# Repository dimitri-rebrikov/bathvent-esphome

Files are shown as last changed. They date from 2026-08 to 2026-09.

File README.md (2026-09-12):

# bathvent-esphome

Automatisierte Lüftungssteuerung für das Bad auf Basis von ESPHome (ESP8266/ESP32) mit MQTT-Anbindung.

## Ziele

Das Projekt steuert die Lüftung eines Bads automatisch anhand von Luftfeuchte und Luftqualität. Die Lüftung soll anwesenheitsabhängig arbeiten – bei Anwesenheit niedrige bis mittlere Stufe, bei Abwesenheit volle Leistung bei überschrittener Schwelle. Schwellwerte und Zeiten sollen zur Laufzeit anpassbar sein; bei Sensorausfall soll die Lüftung weiter funktionieren.

## Umsetzungsideen / Prinzipien

Die Regelung ist eine kleine Zustandsmaschine mit vier Zuständen (`off`, `flush`, `sniff`, `run`) — vollständige Beschreibung inklusive Ablaufdiagramm: [`docs/state-machine.md`](docs/state-machine.md).

Anwesenheit wird über den Lichtschalter erkannt. Bei Anwesenheit startet eine Spülfahrt auf der niedrigsten Stufe; sie spült den Kanal, damit die Messwerte nicht durch zurückströmende Außenluft verfälscht sind. Danach wird gemessen: überschreitet ein Wert seine Schwelle, schaltet der Lüfter auf die mittlere Stufe (begrenzt die Geräuschentwicklung), bei Abwesenheit auf volle Stufe. Bei sauberer Luft und Anwesenheit bleibt er auf der niedrigsten Stufe, bei Abwesenheit aus. Nach dem Ausschalten des Lichts läuft er noch eine Weile auf der niedrigsten Stufe nach; nach langer Abwesenheit wird in Abständen eine Spül-/Messfahrt ausgeführt.

Die Schwellen sind **absolut** (keine gleitende Baseline): Ein Lauf endet, wenn sich in einem vollen Prüfintervall kein Sensorwert mehr signifikant ändert. Das Prüfintervall übernimmt damit die Rolle der Hysterese und begrenzt zugleich, wie oft der Lüfter bei anhaltend feuchter Außenluft anläuft (Frequenz ≈ Prüfintervall + Leerlaufzeit + Spülzeit).

Die drei Stufen werden über eine Kaskadenschaltung realisiert: niedrige und mittlere Stufe über Serien-Kondensatoren, volle Stufe direkt. Die Kaskade verhindert den Kurzschluss der geladenen Kondensatoren, der die Relais beschädigen würde (Festkleben der Kontakte).

Der Feuchtesensor (DHT20) ist der einzige fail-safe-relevante Sensor: Antwortet er nicht (`NAN`), wird sein Messwert durch einen konfigurierbaren Ersatzwert **oberhalb** der Schwelle ersetzt — der Lüfter lüftet dann defensiv weiter (bei Anwesenheit mittlere Stufe, sonst periodischer Volllast-Lauf). Der VOC-Sensor (SGP40) ist optional; sein Ersatzwert liegt **unter** der Schwelle, ein fehlender Sensor wird also ignoriert und die Regelung läuft nur über Feuchte und Licht. Alle Parameter sind über MQTT zur Laufzeit änderbar und bleiben über Neustarts erhalten.

---

## Stufen

Drei Stufen über eine Kaskadenschaltung (Serien-Kondensatoren, Lüfter = 2-Draht-Schattenpolmotor):

| Stufe | Kapazität |
| :--- | :--- |
| LOW | 3 µF |
| MID | 5 µF |
| FULL | direkt |

Die Kapazitäten 3 µF und 5 µF sind experimentell ermittelt und müssen für jeden Ventilator durch Berechnung und Ausprobieren bestimmt werden. Höhere Kombinationen (z. B. 10 µF) laufen bereits praktisch auf Vollgas.

Zuordnung der Stufen zu den Relais:

| Stufe | Master (Ein/Aus) | Full (Voll/Reduziert) | LowMid (Low/Mid) |
| :--- | :--- | :--- | :--- |
| OFF | aus | (egal) | (egal) |
| LOW | an | reduziert | low |
| MID | an | reduziert | mid |
| FULL | an | voll | (egal) |

## Regelung

Ein absoluter Schwellwert pro Sensor (`humidity_threshold`, `voc_threshold`). Ablaufdiagramm, Parameter und Namens-Mapping: [`docs/state-machine.md`](docs/state-machine.md).

| Situation | Stufe |
| :--- | :--- |
| Anwesenheit (Licht), sauber | LOW |
| Anwesenheit, über Schwelle | MID |
| Abwesenheit, über Schwelle | FULL |
| Abwesenheit, sauber | Aus (Spül-/Messfahrt alle `max_off_time`) |
| Nachlauf nach Licht aus (`afterrun_duration`) | LOW |
| Feuchtesensor-Ausfall (Ersatzwert über Schwelle) | wie „über Schwelle“: MID (anwesend) / FULL (abwesend) |
| VOC-Sensor fehlt (Ersatzwert unter Schwelle) | wird ignoriert |

Ein Lauf endet nicht an einer unteren Schwelle, sondern wenn sich in einem vollen Prüfintervall (`change_check_interval`) kein Sensorwert mehr um mehr als sein eigenes `*_change_threshold` bewegt hat. Das ist die bewusste Vereinfachung gegenüber einer gleitenden Baseline: Die Baseline war in der Praxis entweder zu hoch (Bad blieb feucht) oder zu niedrig (Lüfter lief permanent). Der Preis: Bei anhaltend feuchter Außenluft läuft der Lüfter periodisch an, statt dauerhaft durchzulaufen — die Frequenz ist über `change_check_interval`, `max_off_time` und `flush_duration` einstellbar.

Bewertet wird nur im Zustand `sniff`, also nach einer Kanal-Spülung (`flush_duration`). Bei stehendem Lüfter kann Außenluft durch den Kanal zurückströmen und die Rohwerte verfälschen — deshalb wird im Standstill nichts bewertet.

Der SGP40 (VOC) ist optional: liefert er keine gültigen Werte (nicht verlötet oder nicht antwortend), greift die Regelung nur auf Feuchte und Licht zurück.

---

## ESPHome

**GPIO:**

| Funktion | Pin |
| :--- | :--- |
| Optokoppler (Licht), `inverted: true` | GPIO13 (D7) |
| Relay Master (Ein/Aus) | GPIO14 (D5) |
| Relay LowMid (Low/Mid) | GPIO16 (D0) |
| Relay Full (Voll/Reduziert) | GPIO12 (D6) |

**MQTT:** `mqtt.discovery: true`, Topics unter `bathvent/` (`bathvent/<komponente>/<object_id>/state` = lesen, `.../command` = setzen). Alle Schwellwerte und Zeiten sind `number`-Entitäten (`bathvent/number/.../command`, `restore_value: true`). Es gibt keinen manuellen Betriebsmodus mehr — die Regelung läuft immer automatisch. Alle lesbaren und setzbaren Werte: siehe Abschnitt „MQTT“.

**Dateien:**
- `bathvent.yaml` – Hauptdatei (Plattform, Pins, bindet die C++-Logik per `esphome: includes:` ein)
- `bathvent.h` / `bathvent.cpp` – Hardware-unabhängige Zustandsmaschine (`bathvent_tick()`), einmal pro Sekunde aus dem Intervall-Lambda aufgerufen; der gesamte persistente Zustand liegt in einem Modul-Global in `bathvent.cpp`
- `tests/bathvent_test.cpp` – Host-Tests der Zustandsmaschine (siehe Abschnitt „Tests“)
- `common/wifi_mqtt.yaml` – WiFi, MQTT, OTA, captive_portal
- `common/base_esp8266.yaml` – I2C-Bus
- `packages/bathvent_logic.yaml` – Entity-Verdrahtung + 1-s-Intervall-Lambda (I/O-Anbindung an `bathvent_tick()`)
- `docs/state-machine.md` – autoritative Beschreibung der Regelung (Diagramm + Parameter)
- `secrets.yaml` – Zugangsdaten (nicht committen)

## MQTT

Alle Entitäten erscheinen über Discovery automatisch in Home Assistant (`mqtt.discovery: true`). Themenstruktur:

```
bathvent/<komponente>/<object_id>/state    # lesen (Zustand)
bathvent/<komponente>/<object_id>/command  # setzen (Befehl)
```

Befehle laufen über `/command` — `/set` wird ignoriert (ESPHome 2026.x). Parameter mit `restore_value: true` bleiben über Neustarts erhalten.

### Lesbare Werte

| Entity | Komponente | Topic (state) | Bedeutung |
| :--- | :--- | :--- | :--- |
| Temperature | sensor | `bathvent/sensor/temperature/state` | Raumtemperatur (Rohwert, 5-s-Takt) |
| Humidity | sensor | `bathvent/sensor/humidity/state` | relative Luftfeuchte (Rohwert) |
| VOC Index | sensor | `bathvent/sensor/voc_index/state` | VOC-Index (SGP40, optional) |
| Fan State | text_sensor | `bathvent/text_sensor/fan_state/state` | `off` / `flush` / `sniff` / `run` |
| Stage | text_sensor | `bathvent/text_sensor/stage/state` | aktive Stufe: OFF/LOW/MID/FULL |
| Trace | text_sensor | `bathvent/text_sensor/trace/state` | kurzer Ablauf-Trace des Ticks |
| Stored Humidity | sensor | `bathvent/sensor/stored_humidity/state` | Referenzwert des Change-Checks |
| Stored VOC Index | sensor | `bathvent/sensor/stored_voc_index/state` | Referenzwert des Change-Checks |
| Last Sensor Check Age | sensor | `bathvent/sensor/last_sensor_check_age/state` | Alter des Prüfintervall-Starts (s) |
| Last On Age | sensor | `bathvent/sensor/last_on_age/state` | Alter seit der letzten aktiven Stufe (s) |
| Afterrun Age | sensor | `bathvent/sensor/afterrun_age/state` | Alter seit der letzten Anwesenheit im `sniff` (s) |
| Flush Age | sensor | `bathvent/sensor/flush_age/state` | Alter seit dem Start der Spülung (s) |
| Light Switch | binary_sensor | `bathvent/binary_sensor/light_switch/state` | Licht / Anwesenheit |
| Relay Master / LowMid / Full | switch | `bathvent/switch/relay_<id>/state` | Relais-Zustand |

Die Roh-Sensoren (Temperature/Humidity/VOC) publizieren kontinuierlich (eigener
5-s-Takt) und können im Standstill durch Rückströmung im Kanal verfälscht sein.
`Fan State`, `Stage`, `Trace` sowie die Referenz- und Alterswerte kommen aus dem
1-s-Tick der Regelung; der `Trace` bewusst bei **jedem** Tick, damit der Ablauf
lückenlos nachvollziehbar ist.

### Setzbare Werte

| Parameter | Topic (command) | Bereich | Schritt | Default | Bedeutung |
| :--- | :--- | :--- | :--- | :--- | :--- |
| Humidity Threshold | `bathvent/number/humidity_threshold/command` | 30–90 % | 1 | 65 | absolute Feuchte-Schwelle |
| VOC Threshold | `bathvent/number/voc_threshold/command` | 101–400 | 5 | 150 | VOC-Schwelle |
| Humidity Change Threshold | `bathvent/number/humidity_change_threshold/command` | 0.1–5 % | 0.1 | 1 | Mindeständerung pro Prüfintervall |
| VOC Change Threshold | `bathvent/number/voc_change_threshold/command` | 1–50 | 1 | 10 | Mindeständerung pro Prüfintervall |
| Change Check Interval | `bathvent/number/change_check_interval/command` | 60–900 s | 30 | 300 | Prüfintervall und Mindestlaufzeit |
| Max Off Time | `bathvent/number/max_off_time/command` | 300–7200 s | 60 | 1800 | Leerlauf bis zur periodischen Messfahrt |
| Flush Duration | `bathvent/number/flush_duration/command` | 15–120 s | 5 | 30 | Kanal-Spülung vor einer Messung |
| Afterrun Duration | `bathvent/number/afterrun_duration/command` | 60–600 s | 10 | 300 | Nachlauf nach Licht aus |
| Humidity NaN Value | `bathvent/number/humidity_nan_value/command` | 0–200 | 1 | 101 | Fail-safe-Ersatzwert Feuchte (über Schwelle = lüften) |
| VOC NaN Value | `bathvent/number/voc_nan_value/command` | 0–500 | 1 | 0 | Fail-safe-Ersatzwert VOC (unter Schwelle = ignorieren) |
| Relay Master / LowMid / Full | `bathvent/switch/relay_<id>/command` | – | – | – | ON/OFF (wird jeden Tick überschrieben) |

Hinweis: `restore_value: true` heißt, ein bereits auf dem Gerät gespeicherter
Wert **gewinnt** gegenüber einem geänderten Default nach dem Flashen. Neue
Defaults wirken erst nach einem Flash-Wipe oder nach einmaligem Setzen per MQTT.

Die Spalten „Bereich“/„Schritt“ sind **MQTT-Payloads**: Dezimalzahlen mit
**Punkt** senden (`0.1`), nicht mit Komma. ESPHome parst die Nutzlast mit `.` als
Dezimaltrenner — `0,1` wird verworfen und der Befehl bleibt wirkungslos.

## Hardware

Stückliste:

| # | Bauteil | Spezifikation | Menge | Funktion |
| :--: | :--- | :--- | :--: | :--- |
| 1 | ESP8266 (Wemos D1 Mini) | – | 1 | Steuerung |
| 2 | Netzteil | 5 V DC | 1 | Versorgung |
| 3 | DHT20 | Temperatur und Feuchte, I2C | 1 | Sensor |
| 4 | SGP40 | VOC-Index, I2C | 1 (optional) | Sensor |
| 5 | Optokoppler-Modul | – | 1 | Lichterkennung |
| 6 | Relais-Module (Kaskade) | Master, Full, LowMid | 3 | Stufenschaltung |
| 7 | Kondensator | 3 µF, 450 V AC | 1 | LOW-Stufe |
| 8 | Kondensator | 5 µF, 450 V AC | 1 | MID-Stufe |
| 9 | NTC-Heißleiter | 10 Ω, Kopf Ø 9 mm | 1 | Anlaufstrombegrenzung (FULL) |
| 10 | RC-Glied | 0,1 µF / 100 Ω, 0,5 W, 600 V AC | 1 | Lichtbogen-Unterdrückung (parallel zum Lüfter) |
| 11 | Lüfter | 2-Draht-Schattenpolmotor | 1 | Belüftung |

PSC-, EC- und Universalmotoren verhalten sich mit Serien-Kondensatoren anders und sind nicht abgedeckt.

## Verdrahtung

**DC-Seite (Kleinspannung):**

| # | Von | Pin | Nach |
| :--: | :--- | :--- | :--- |
| 1 | DHT20 | SDA | GPIO4 (D2) |
| 2 | DHT20 | SCL | GPIO5 (D1) |
| 3 | SGP40 (optional) | SDA | GPIO4 (D2) |
| 4 | SGP40 (optional) | SCL | GPIO5 (D1) |
| 5 | DHT20 | VCC | 3,3 V |
| 6 | SGP40 (optional) | VCC | 3,3 V |
| 7 | DHT20 | GND | GND |
| 8 | SGP40 (optional) | GND | GND |
| 9 | Optokoppler (Licht) | OUT | GPIO13 (D7) |
| 10 | Optokoppler (Licht) | VCC | 5 V |
| 11 | Optokoppler (Licht) | GND | GND |
| 12 | Relay Master (Ein/Aus) | IN | GPIO14 (D5) |
| 13 | Relay LowMid (Low/Mid) | IN | GPIO16 (D0) |
| 14 | Relay Full (Voll/Reduziert) | IN | GPIO12 (D6) |
| 15 | Relais-Module | VCC | 5 V |
| 16 | Relais-Module | GND | GND |
| 17 | ESP8266 | VIN | 5 V |
| 18 | ESP8266 | GND | GND |
| 19 | Netzteil (5 V) | +5 V | 5 V (Versorgungsschiene) |
| 20 | Netzteil (5 V) | GND | GND |

Alle GND-Potenziale der DC-Seite verbinden (gemeinsame Masse). Sensoren auf 3,3 V (nicht 5 V).

**AC-Seite (230 V):**

| # | Von | Kontakt | Nach |
| :--: | :--- | :--- | :--- |
| 1 | L (Dauerphase) | – | Relay Master COM |
| 2 | Relay Master (Ein/Aus) | NO | Relay Full COM |
| 3 | Relay Full (Voll/Reduziert) | NC (voll) | NTC (10 Ω) |
| 4 | NTC (10 Ω) | – | Lüfter L |
| 5 | Relay Full (Voll/Reduziert) | NO (reduziert) | Relay LowMid COM |
| 6 | Relay LowMid (Low/Mid) | NO (mid) | 5 µF |
| 7 | 5 µF | – | Lüfter L |
| 8 | Relay LowMid (Low/Mid) | NC (low) | 3 µF |
| 9 | 3 µF | – | Lüfter L |
| 10 | RC-Glied (0,1 µF / 100 Ω) | – | Lüfter L (parallel zum Motor) |
| 11 | RC-Glied (0,1 µF / 100 Ω) | – | Lüfter N (parallel zum Motor) |
| 12 | N | – | Lüfter N |
| 13 | N | – | Netzteil (5 V) |
| 14 | N | – | Optokoppler |
| 15 | L (Dauerphase) | – | Netzteil (5 V) |
| 16 | LH (Lampenphase) | – | Optokoppler |

Kontakte: COM = gemeinsamer Kontakt (Anker), NO = Arbeitskontakt/Schließer (Relais angezogen), NC = Ruhekontakt/Öffner (Relais abgefallen). 230-V-Arbeiten nur durch Fachpersonal.

**Schaltplan:** `docs/circuit-diagram.schemdraw.py` erzeugt `docs/circuit-diagram.svg`/`.png` (Dependencies per PEP-723-Inline-Metadaten deklariert):

```
uv run docs/circuit-diagram.schemdraw.py     # aus dem Projekt-Root
cd docs && uv run circuit-diagram.schemdraw.py   # alternativ aus dem docs-Ordner
```

Hinweis: `uvx` startet Tools (`uv tool run`), `uv run` startet Skripte – für PEP-723-Skripte ist `uv run` der richtige Befehl.

---

## KI-Metadaten (für AI-Agenten)

## Tests

Die Regelung ist hardwareunabhängig und läuft auf dem PC gegen synthetische
Messwerte und eine synthetische Uhr — Nachlauf (5 min) und periodische Messfahrt
(30 min) werden in Millisekunden geprüft, ohne zu warten:

```
g++ -std=c++17 -Wall -Wextra -DBATHVENT_HOST_TEST -I. -o tests/bathvent_test tests/bathvent_test.cpp bathvent.cpp
./tests/bathvent_test
```

Abgedeckt: Dauerbetrieb LOW/MID ohne Takten, periodischer FULL-Puls bei
Abwesenheit, Nachlauf nach Licht aus, Fail-safe bei totem Feuchtesensor,
ignorierter VOC-Sensor, Zeitstempel-Überlauf (`millis()`), Trace-Format
(Entscheidung + Actions) und Trace-Länge (keine Truncation).

---

## KI-Metadaten (für AI-Agenten)

- ESPHome 2026.7.x, CLI via `uvx esphome`; Boards `d1_mini` / `nodemcuv2` / `esp32dev`.
- Steuerlogik: Zustandsmaschine in `bathvent.h`/`bathvent.cpp` (`bathvent_tick()`), per `esphome: includes:` eingebunden, 1×/s aus dem Intervall-Lambda in `packages/bathvent_logic.yaml`. Autoritative Beschreibung + Ablaufdiagramm: `docs/state-machine.md`.
- Zustände `off`/`flush`/`sniff`/`run` (Enum `FanState`); Stufen `0=Aus, 1=LOW(3µF), 2=MID(5µF), 3=FULL(direkt)` (Enum `Stage`). Zuordnung: `run` → MID (anwesend) / FULL (abwesend); `flush`/`sniff` → LOW. Jede Stufe ≠ OFF setzt `last_on_ts`.
- Ablauf: `off` + Anwesenheit oder `max_off_time` abgelaufen → `flush`; nach `flush_duration` → `sniff`; Wert über Schwelle → `run`, sonst bei Anwesenheit Nachlauf (LOW, `afterrun_duration` nach dem letzten Presence-Tick im Sniff) und bei Abwesenheit Aus. `run` läuft, solange `now - last_sensor_check_ts <= change_check_interval`; danach entscheidet, ob sich irgendein Wert um mehr als sein eigenes `*_change_threshold` bewegt hat (ja → Referenz aktualisieren, weiter; nein → anwesend: Sniff-Entscheidung im **selben** Tick, abwesend: Aus).
- **Keine Baseline/EMA, keine Hysterese, kein manueller Modus** (bewusst entfernt: die Baseline war praktisch entweder zu hoch — Bad blieb feucht — oder zu niedrig — Dauerlauf). Das Prüfintervall ist die Dämpfung; bei anhaltend feuchter Außenluft läuft der Lüfter periodisch.
- Fail-safe = NaN-Policy: `NAN` wird durch `humidity_nan_value` (101, über der Schwelle → lüften) bzw. `voc_nan_value` (0, unter der Schwelle → ignorieren) ersetzt. Ein konstanter Ersatzwert gilt nach einem Intervall als „stabil" — bei Anwesenheit fängt das der `run`-Zweig ab, bei Abwesenheit entsteht der gewollte periodische FULL-Puls.
- Zeit: `BathventInputs::now_s = millis() / 1000`; alle Vergleiche über `(uint32_t)(now - t)` (überlaufsicher). Zustand in `g_state` (`bathvent.cpp`), Reset via `bathvent_reset_state()`; Zeitstempel werden beim ersten Tick auf `now_s` gepinnt.
- Logging: `BV_LOG(...)` = `ESP_LOGD("bathvent", ...)` bzw. No-op unter `-DBATHVENT_HOST_TEST` (mit `-DBATHVENT_HOST_LOG` auf stdout). Trace: `char[320]` in `bathvent.cpp`, pro Tick geleert und in `BathventResult::trace` zurückgegeben; im Lambda als Text-Sensor `trace` bei jedem Tick publiziert. Format `<Zustand>|<entscheidung>(<eingangsparameter>)<yes|no>|…|<action>|…` — jede Entscheidung mit Eingangsparametern und Ergebnis, danach jede Action; das Log enthält dieselben Informationen als Langtext (`decide … -> YES|NO`, `action …`). Token- und Parameter-Tabellen: `docs/state-machine.md`.
- `ota:` mit `- platform: esphome`; DHT20 als `aht10` mit `variant: AHT20`; `sgp4x` mit `voc_index`; Entity-Namen ohne `/`.
- Kaskade: `relay_master` (Ein/Aus), `relay_full` (Voll/Reduziert; NC = voll/direkt via NTC, NO = reduziert/Bank), `relay_lowmid` (Low/Mid; NC = 3µF, NO = 5µF); nur `kOff` schaltet `relay_master` aus; de-energized `relay_full` = voll.
- Sensoren: DHT20 (Feuchte **absolut**) + SGP40 (VOC 1–500, 100 = 24h-Mittel, `store_baseline: true`, optional), Kompensation vom DHT20. Roh-Sensoren publizieren im 5-s-Takt; bewertet wird nur nach der Kanal-Spülung.
- Defaults (`number`, MQTT-setbar, `restore_value: true`): `humidity_threshold=65`, `voc_threshold=150`, `humidity_change_threshold=1`, `voc_change_threshold=10`, `change_check_interval=300`, `max_off_time=1800`, `flush_duration=30`, `afterrun_duration=300`, `humidity_nan_value=101`, `voc_nan_value=0`.
- MQTT: Topics `bathvent/.../state` (lesen) + `bathvent/.../command` (setzen); Befehle NICHT über `/set`. Kein `select` mehr (kein manueller Modus).
- Tests: `g++ -std=c++17 -DBATHVENT_HOST_TEST -I. -o tests/bathvent_test tests/bathvent_test.cpp bathvent.cpp && ./tests/bathvent_test`.

---

## Installation

Voraussetzung: ESPHome 2026.7.x (ohne lokales venv, z. B. via `uvx`). Zugangsdaten in `secrets.yaml` eintragen (nicht committen).

```
uvx esphome run bathvent.yaml --device COMx   # erstes Flashen per USB
uvx esphome run bathvent.yaml                 # danach per OTA
```

Bei CH340-Fehler `Error 31` unter Windows: Treiber v3.5.2019.1 verwenden und Windows-Driver-Updates blockieren.

## Quellen

- ESPHome: https://esphome.io/
  - OTA: https://esphome.io/components/ota.html
  - AHT10/DHT20: https://esphome.io/components/sensor/aht10.html
  - SGP4x: https://esphome.io/components/sensor/sgp4x.html
  - Select: https://esphome.io/components/select/
  - Captive Portal: https://esphome.io/components/captive_portal/
  - GPIO-Switch: https://esphome.io/components/switch/gpio.html
  - GPIO-Binary-Sensor: https://esphome.io/components/binary_sensor/gpio.html
  - Kommandozeile: https://esphome.io/guides/getting_started_command_line.html
- Wikipedia – Spaltpolmotor: https://de.wikipedia.org/wiki/Spaltpolmotor
- Wikipedia – Kondensatormotor: https://de.wikipedia.org/wiki/Kondensatormotor

## Lizenz

MIT, siehe `LICENSE`.

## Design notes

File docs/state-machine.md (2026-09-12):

# Regelung — Zustandsmaschine

Autoritative Beschreibung der Lüfterregelung. Bei jeder Logikänderung müssen
dieses Diagramm, die Tabellen hier und die Implementierung in `bathvent.h` /
`bathvent.cpp` **zusammen** aktualisiert werden.

Kurzfassung: Der Lüfter kennt vier Zustände (`off`, `flush`, `sniff`, `run`) und
drei Stufen (LOW, MID, FULL). Es gibt **keine Baseline/EMA** — die Schwellen
sind absolut. Statt einer Pegel-Hysterese dämpft das **Prüfintervall**
(`change_check_interval`): ein Lauf endet erst, wenn sich in einem vollen
Intervall kein Sensorwert mehr signifikant bewegt hat. Messwerte sind nur nach
einer Kanal-Spülung vertrauenswürdig — bei stehendem Lüfter kann Außenluft
durch den Kanal zurückströmen und die Werte verfälschen.

## Diagramm

```mermaid
flowchart TD
    start([Start]) --> read_current_sensor_value[fill SensorCurrentValue for every sensor, if NAN fill with ConfigSensorNanValue of corresponding Sensor]
    read_current_sensor_value --> fan_state_check{Fan State Check}

    fan_state_check -- run --> running_time_check{CurrentTime - LastSensorCheckTimestamp > ConfigSensorChangeCheckInterval ? }
    running_time_check -- yes --> sensor_change_check{"Is for any sensor: abs(SensorStoredValue - SensorCurrentValue) > ConfigSensorChangeThreshold (separate value for each sensor)"}
    running_time_check -- no --> fan_run[Fan Run]
    sensor_change_check -- no --> fan_off_presence_check{"Is human present"}
    fan_off_presence_check -- yes --> sensor_check
    fan_off_presence_check -- no --> fan_off
    sensor_change_check -- yes --> fan_start_run
    fan_start_run --> update_stored_sensor_values[Update SensorStoredValue with SensorCurrentValue for every sensor]
    update_stored_sensor_values --> reset_last_sensor_check_timestamp[LastSensorCheckTimestamp = CurrentTime]
  
    fan_state_check -- off --> flush_presence_check{Is human present}
    flush_presence_check -- yes --> start_flush[Start Flush]
    flush_presence_check -- no --> time_for_control_run_check{CurrentTime - LastOnTimestamp > ConfigMaxOffTime}
    time_for_control_run_check -- yes --> start_flush
    time_for_control_run_check -- no --> fan_off

    fan_state_check -- sniff --> sensor_check{Check SensorCurrentValue for every sensor }
    sensor_check -- "any value is above its ConfigSensorThresholdValue" --> fan_start_run
    sensor_check -- "all values are below their respective ConfigSensorThresholdValue" --> sniff_presence_check{Is human present}
    sniff_presence_check -- yes --> reset_after_run_timestamp[AfterRunTimestamp = CurrentTime]
    reset_after_run_timestamp --> fan_sniff
    sniff_presence_check -- no --> after_run_finished_check{CurrentTime - AfterRunTimestamp > ConfigAfterRunDuration}
    after_run_finished_check -- yes --> fan_off
    after_run_finished_check -- no --> fan_sniff

    fan_state_check -- flush --> time_to_sniff_check{CurrentTime - FlushStartedTimestamp > ConfigFlushDuration}
    time_to_sniff_check -- yes --> fan_sniff[Sniff]
    time_to_sniff_check -- no --> keep_flush[Keep Flush]

    fan_start_run --> fan_run
    fan_run --> run_full_level_check{Is human absent}
    run_full_level_check -- yes --> run_fan_on_full[Run Fan on FULL level]
    run_full_level_check -- no --> run_fan_on_mid[Run Fan on MID level]

    start_flush --> reset_flush_started_timestamp[FlushStartedTimestamp = CurrentTime]
    start_flush --> run_fan_on_low[Run Fan on LOW level]
    keep_flush --> run_fan_on_low
    fan_sniff --> run_fan_on_low

    run_fan_on_low --> reset_last_on_timestamp[LastOnTimestamp = CurrentTime]
    run_fan_on_mid --> reset_last_on_timestamp[LastOnTimestamp = CurrentTime]
    run_fan_on_full --> reset_last_on_timestamp[LastOnTimestamp = CurrentTime]
```
## Zustände und Stufen

| Zustand | Stufe | Bedeutung |
| :--- | :--- | :--- |
| `off` | OFF | Aus. Wartet auf Anwesenheit oder Ablauf von `max_off_time`. |
| `flush` | LOW | Kanal spülen (`flush_duration`), damit die Messwerte vertrauenswürdig sind. |
| `sniff` | LOW | Messfahrt: ein Wert über seiner Schwelle startet `run`, sonst Nachlauf oder Aus. |
| `run` | MID (anwesend) / FULL (abwesend) | Lüftung; läuft, solange sich ein Wert pro Intervall signifikant ändert. |

## Ablauf pro Tick (1 s)

1. **Messwerte lesen.** `NAN` (Sensor antwortet nicht) wird durch
   `humidity_nan_value` bzw. `voc_nan_value` ersetzt — das ist die
   Fail-safe-Policy (siehe unten).
2. **Zustand entscheiden** — pro Tick genau ein Zweig:

**`run`**
- `now - last_sensor_check_timestamp <= change_check_interval` → weiter MID/FULL.
- sonst: hat sich irgendein Wert um mehr als sein eigenes
  `*_change_threshold` bewegt?
  - ja → Referenzwerte aktualisieren, Intervall neu starten, weiter MID/FULL.
  - nein → anwesend? → **im selben Tick** die Sniff-Entscheidung auswerten
    (statt einfach auszuschalten); abwesend → `off`.

**`off`**
- anwesend → `flush` starten.
- sonst `now - last_on_timestamp > max_off_time` → `flush` starten
  (periodischer Luftaustausch), sonst aus bleiben.

**`sniff`**
- irgendein Wert über seiner Schwelle → `run` starten.
- sonst: anwesend → `after_run_timestamp = now`, weiter `sniff` (LOW);
  abwesend → `now - after_run_timestamp > afterrun_duration` ? → `off`
  : weiter `sniff` (LOW).

**`flush`**
- `now - flush_started_timestamp > flush_duration` → `sniff`, sonst weiter LOW.

Jede Stufe ungleich OFF setzt `last_on_timestamp = now`.

## Verhalten in typischen Situationen

| Situation | Verhalten |
| :--- | :--- |
| Anwesend, sauber | Dauerhaft LOW (`sniff`), ohne Takten |
| Anwesend, feucht | Dauerhaft MID, bis der Wert unter die Schwelle fällt |
| Abwesend, feucht | FULL, bis sich nichts mehr ändert; danach aus |
| Abwesend, sauber | Aus; alle `max_off_time` eine Flush-/Messfahrt |
| Licht aus nach sauberem Betrieb | `afterrun_duration` lang LOW, dann aus |
| Feuchtesensor tot | Wert liegt über der Schwelle → lüften (MID/FULL) |
| VOC-Sensor fehlt | Wert liegt unter der Schwelle → wird ignoriert |

## Konfiguration

Alle Parameter sind MQTT-`number`-Entitäten (`restore_value: true`). Die
kompilierten Defaults stehen in `BathventConfig` (`bathvent.h`); die
`initial_value` in `packages/bathvent_logic.yaml` müssen dazu passen.

| Parameter (YAML-Id) | Default | Bereich (Step) | Bedeutung |
| :--- | :--- | :--- | :--- |
| `humidity_threshold` | 65 % | 30–90 (1) | absolute Feuchte-Schwelle |
| `voc_threshold` | 150 | 101–400 (5) | VOC-Schwelle |
| `humidity_change_threshold` | 1 % | 0.1–5 (0.1) | Mindeständerung pro Intervall |
| `voc_change_threshold` | 10 | 1–50 (1) | Mindeständerung pro Intervall |
| `change_check_interval` | 300 s | 60–900 (30) | Prüfintervall **und** Mindestlaufzeit |
| `max_off_time` | 1800 s | 300–7200 (60) | Leerlauf bis zur periodischen Messfahrt |
| `flush_duration` | 30 s | 15–120 (5) | Kanal-Spülung vor einer Messung |
| `afterrun_duration` | 300 s | 60–600 (10) | LOW-Fenster nach Presence-Ende |
| `humidity_nan_value` | 101 | 0–200 (1) | Fail-safe-Wert Feuchte |
| `voc_nan_value` | 0 | 0–500 (1) | Fail-safe-Wert VOC |

`restore_value: true` heißt: Ein bereits gespeicherter Wert auf dem Gerät
**gewinnt** gegenüber einem geänderten Default nach dem Flashen. Neue Defaults
wirken dort erst nach einem Flash-Wipe oder nach einmaligem Setzen per MQTT.

Die Werte in der Tabelle sind **MQTT-Payloads**: Dezimalzahlen mit **Punkt**
senden (`0.1`), nicht mit Komma. ESPHome parst die Nutzlast mit `.` als
Dezimaltrenner — `0,1` wird als ungültig verworfen und der Befehl bleibt
wirkungslos. (Nur `humidity_change_threshold` hat überhaupt Nachkommastellen.)

## Fail-safe

Es gibt keine eigene Ausfall-Logik: Ein nicht antwortender Sensor liefert `NAN`,
und `NAN` wird durch den jeweiligen `*_nan_value` ersetzt. Die Ausfall-Policy ist
damit eine Konfigurationsentscheidung:

- **Feuchte über der Schwelle** (101 %) → ein toter Feuchtesensor gilt als
  "feucht", der Lüfter lüftet. Bewusst defensiv: lieber zu viel lüften.
- **VOC unter der Schwelle** (0) → ein fehlender SGP40 (optional) wird
  ignoriert und löst nichts aus.

Achtung: Ein konstanter Ersatzwert ändert sich nie, deshalb gilt ein Lauf mit
totem Sensor nach genau einem Prüfintervall als "stabil". Bei Anwesenheit fängt
der `run`-Zweig das ab (stabil + anwesend → erneut `sensor_check` → weiter MID);
bei Abwesenheit entsteht der gewollte periodische FULL-Puls.

## Trace und Logging

Der Tick ist eine wörtliche Übersetzung dieser Zustandsmaschine. Jede
**Entscheidung** wird mit ihren **Eingangsparametern** und ihrem **Ergebnis**
protokolliert, jede **Action** mit ihrer Wirkung — beides doppelt: ausführlich
im Log ("long text") und als Token im Trace-String ("short text").

- **Log (lang):** `decide <name> <parameter> -> YES|NO` bzw.
  `action <name> <wirkung>`, dazu eine Schlusszeile pro Tick. Auf dem Gerät über
  `ESP_LOGD("bathvent", ...)`; unter `-DBATHVENT_HOST_TEST` ist es ein No-op, mit
  zusätzlichem `-DBATHVENT_HOST_LOG` geht es auf stdout.
- **MQTT (kurz):** `trace` (Text-Sensor, max. 320 Zeichen). Der String wird am
  Anfang jedes Ticks geleert, Token für Token gefüllt und am **Ende des Ticks**
  publiziert — ein "Loop" ist also **ein 1-s-Tick**:

  ```
  <Zustand>|<entscheidung>(<parameter>)<yes|no>|…|<action>|…
  ```

Beispiel (Licht an, feucht — Spülung beendet, Messung entscheidet):

```
[bathvent]   decide flush_time   flushing 31s vs 30s                            -> YES
[bathvent]   action fan_sniff    flush finished
[bathvent]   action run_fan_on_low stage=LOW
[bathvent]   action reset_last_on_ts LastOnTimestamp = now
[bathvent] tick end: state=SNIFF stage=LOW trace=FLUSH|flush_time(flushing 31s vs 30s)yes|fan_sniff|run_fan_on_low|reset_last_on_ts
```

Ein Tick kann mehrere Entscheidungen enthalten (im `run`-Zustand:
Intervall → Änderung → Anwesenheit → Messung), genau in der Reihenfolge des
Diagramms.

**Entscheidungen** (Token → Parameter → Knoten im Diagramm):

| Token | Parameter | Knoten |
| :--- | :--- | :--- |
| `presence` | `light=0\|1` | `flush_presence_check`, `sniff_presence_check`, `fan_off_presence_check` |
| `run_time` | `since check <n>s vs interval <n>s` | `running_time_check` |
| `change` | `dhum <v> vs <thr>, dvoc <v> vs <thr>` | `sensor_change_check` |
| `sensor` | `hum <v> vs <thr>, voc <v> vs <thr>` | `sensor_check` |
| `afterrun_done` | `afterrun <n>s vs <n>s` | `after_run_finished_check` |
| `flush_time` | `flushing <n>s vs <n>s` | `time_to_sniff_check` |
| `off_time` | `idle <n>s vs max_off <n>s` | `time_for_control_run_check` |
| `level` | `light=0\|1` (abwesend?) | `run_full_level_check` |

**Actions** (Token → Wirkung):

| Token | Wirkung |
| :--- | :--- |
| `start_flush`, `reset_flush_ts`, `run_fan_on_low` | Spülung starten (`start_flush`, `reset_flush_started_timestamp`, `run_fan_on_low`) |
| `keep_flush`, `run_fan_on_low` | Spülung fortsetzen |
| `start_run`, `update_stored`, `reset_check_ts` | `fan_start_run`, `update_stored_sensor_values`, `reset_last_sensor_check_timestamp` |
| `run_fan_on_low` / `run_fan_on_mid` / `run_fan_on_full` | Stufe setzen |
| `fan_sniff` | zurück in den Mess-Zustand (`sniff`) |
| `fan_off` | aus |
| `reset_afterrun_ts` | `AfterRunTimestamp = now` |
| `reset_last_on_ts` | `LastOnTimestamp = now` |

Der Puffer ist 320 Zeichen; der längste gemessene Trace (Pfad
`run → change → presence → sensor → start_run`) liegt bei ~250 Zeichen. Der
Host-Test prüft das und schlägt bei Truncation fehl.

## MQTT-sichtbarer Zustand

Alles, was der Controller zwischen Ticks speichert, wird publiziert:

| Entität | Typ | Inhalt |
| :--- | :--- | :--- |
| `Fan State` | text | `off` / `flush` / `sniff` / `run` |
| `Stage` | text | `OFF` / `LOW` / `MID` / `FULL` |
| `Trace` | text | kurzer Trace des Ticks |
| `Stored Humidity` / `Stored VOC Index` | sensor | Referenzwerte des Change-Checks |
| `Last Sensor Check Age` | sensor | Alter des Prüfintervall-Starts |
| `Last On Age` | sensor | Alter seit der letzten aktiven Stufe |
| `Afterrun Age` | sensor | Alter seit der letzten Anwesenheit im `sniff` |
| `Flush Age` | sensor | Alter seit dem Start der laufenden/letzten Spülung |

Die Rohsensoren (`Temperature`, `Humidity`, `VOC Index`) publizieren weiterhin
im eigenen 5-s-Takt; im Standstill können sie durch Rückströmung verfälscht sein.
Verlässlich sind nur Werte nach einer Spülung — der `Trace` zeigt, wann gemessen
wurde.

## Namens-Mapping (Diagramm → Code)

| Diagramm | YAML-Id | `BathventConfig` |
| :--- | :--- | :--- |
| `ConfigSensorThresholdValue` Feuchte | `humidity_threshold` | `humidity_threshold` |
| `ConfigSensorThresholdValue` VOC | `voc_threshold` | `voc_threshold` |
| `ConfigSensorChangeThreshold` | `humidity_change_threshold` / `voc_change_threshold` | dito |
| `ConfigSensorChangeCheckInterval` | `change_check_interval` | `change_check_interval_s` |
| `ConfigMaxOffTime` | `max_off_time` | `max_off_time_s` |
| `ConfigFlushDuration` | `flush_duration` | `flush_duration_s` |
| `ConfigAfterRunDuration` | `afterrun_duration` | `afterrun_duration_s` |
| `ConfigSensorNanValue` | `humidity_nan_value` / `voc_nan_value` | dito |
| `SensorStoredValue` | `Stored Humidity` / `Stored VOC Index` | `g_state.stored_*` |
| `SensorCurrentValue` | Rohsensoren | `BathventInputs` |
| `LastOnTimestamp` | `Last On Age` | `g_state.last_on_ts` |
| `AfterRunTimestamp` | `Afterrun Age` | `g_state.after_run_ts` |
| `FlushStartedTimestamp` | `Flush Age` | `g_state.flush_started_ts` |
| `LastSensorCheckTimestamp` | `Last Sensor Check Age` | `g_state.last_sensor_check_ts` |

## Tests

Die Logik ist hardwareunabhängig und läuft auf dem PC gegen synthetische
Messwerte und eine synthetische Uhr:

```
g++ -std=c++17 -Wall -Wextra -DBATHVENT_HOST_TEST -I. -o tests/bathvent_test tests/bathvent_test.cpp bathvent.cpp
./tests/bathvent_test
```

Abgedeckt: Dauerbetrieb LOW/MID ohne Takten, periodischer FULL-Puls bei
Abwesenheit, Nachlauf nach Licht aus, Fail-safe bei totem Feuchtesensor,
ignorierter VOC-Sensor, Zeitstempel-Überlauf, Trace-Format (Entscheidung mit
Eingangsparametern + Actions) und Trace-Länge.

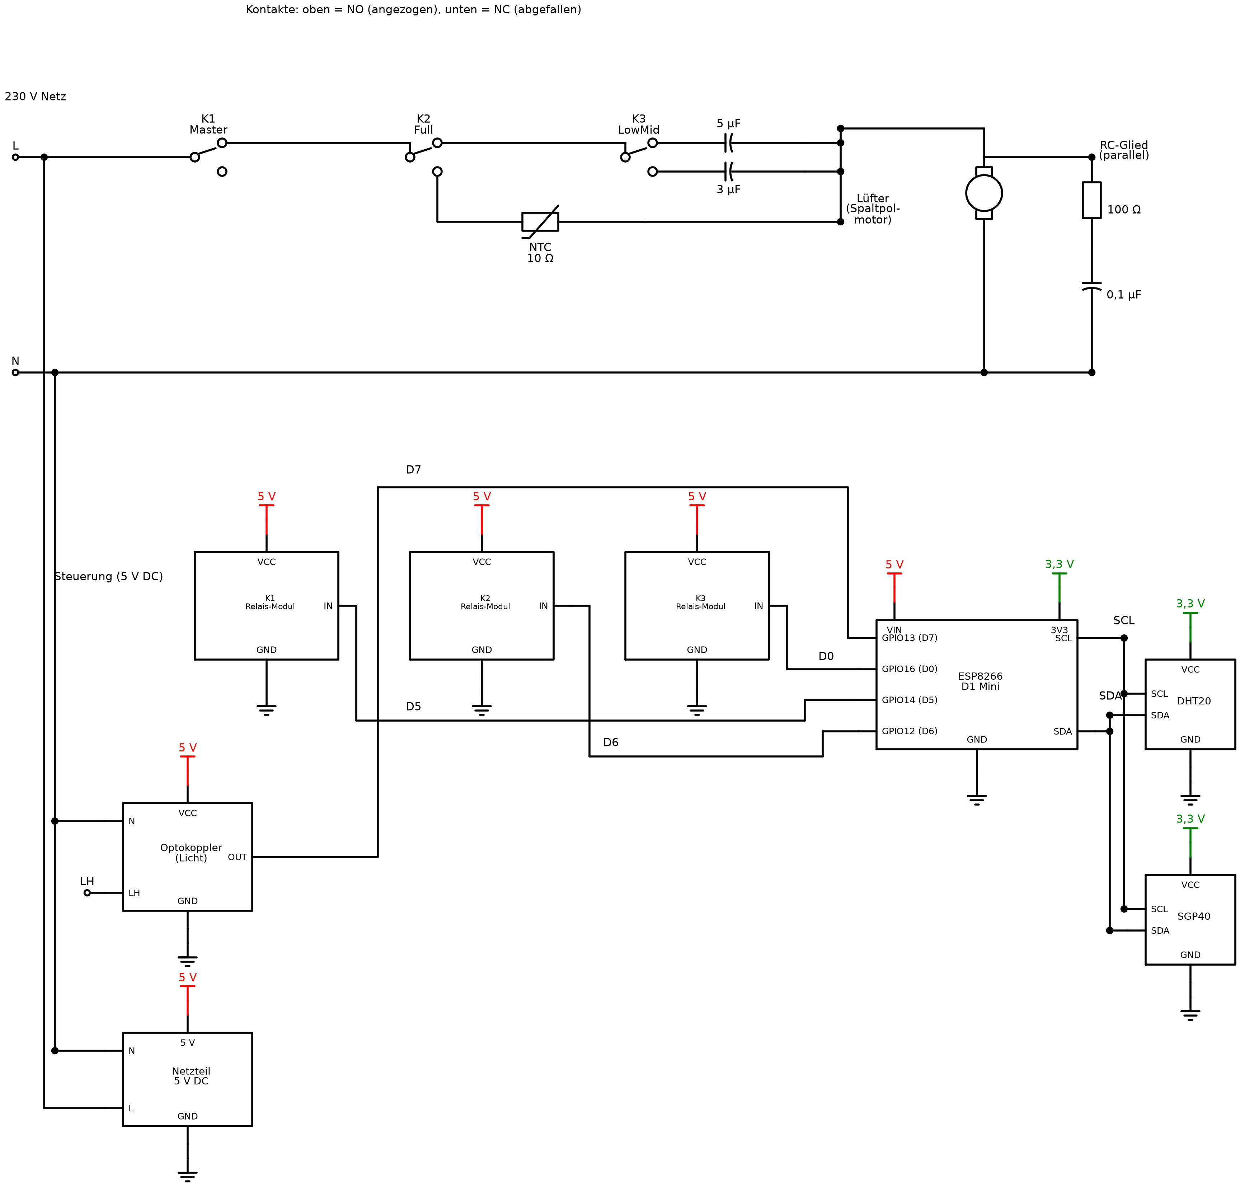
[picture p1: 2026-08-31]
docs/circuit-diagram.png

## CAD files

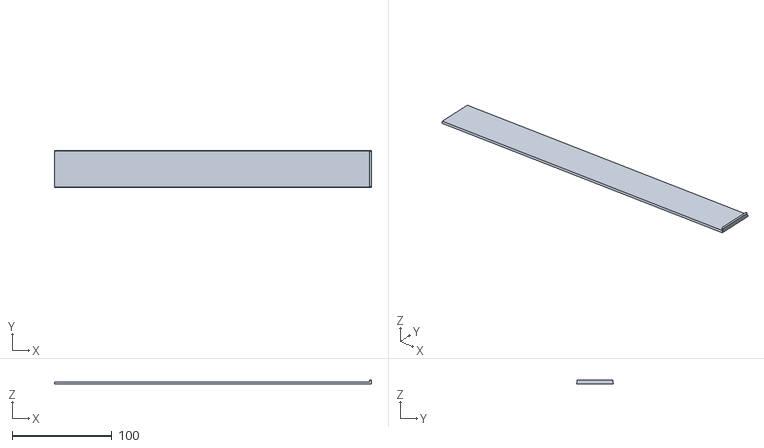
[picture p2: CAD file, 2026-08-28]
assembly/bathvent_lid.stl
317.8 x 37.2 x 4.00

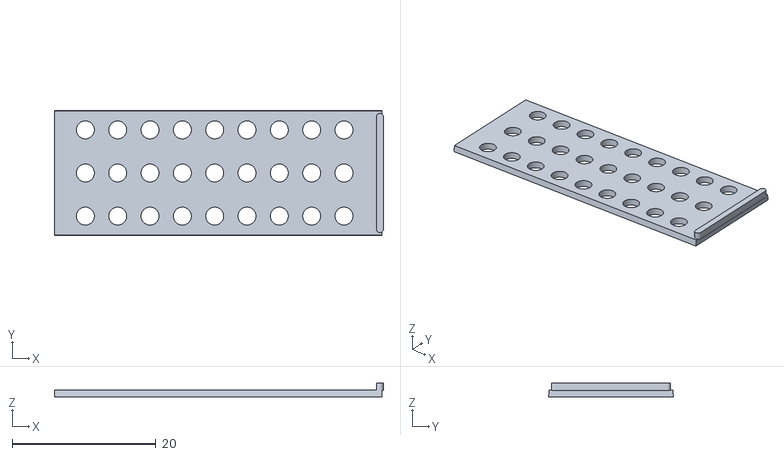
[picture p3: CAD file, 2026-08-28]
assembly/sensor_lid.stl
45.8 x 17.4 x 2.00

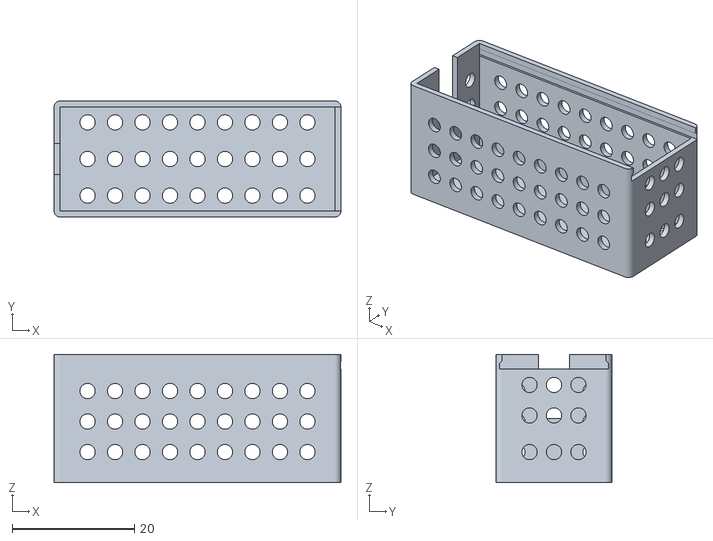
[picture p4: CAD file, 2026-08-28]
assembly/sensor_box.stl
47.0 x 19.0 x 21.0

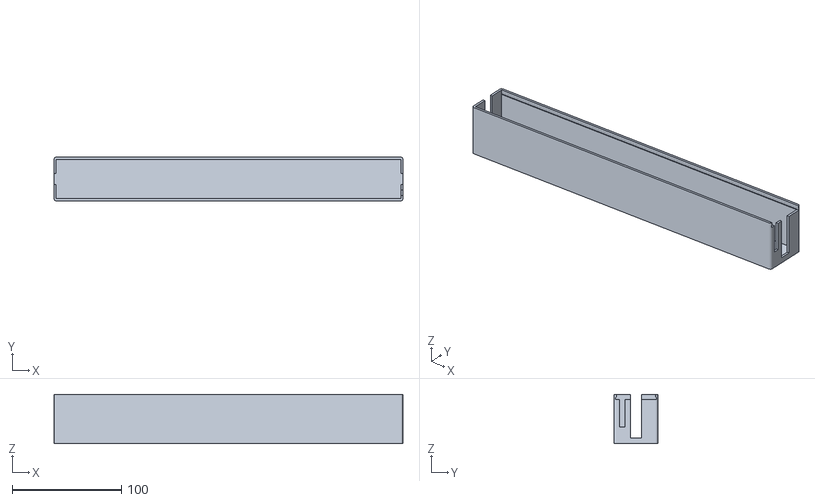
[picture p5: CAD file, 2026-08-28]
assembly/bathvent_box.stl
320.0 x 40.0 x 45.0

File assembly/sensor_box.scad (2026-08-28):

// =============================================================================
// sensor_box.scad — kleines Lüftungsgehäuse für Sensoren (Schiebedeckel-Box)
// =============================================================================
// Gleiche Konstruktion wie bathvent_enclosure.scad (Schiebedeckel-Box) auf Basis
// der Bibliothek
//   ../../3d-models/schiebedeckel-box/schiebedeckel-box.scad  (benötigt BOSL2)
//
// Außenmaße: 47 × 19 × 21 mm (Breite × Tiefe × Höhe), Wandstärke 1 mm.
//
// Aussparungen (nur in der Kiste / box):
//   • Rückwand (-x): Kabel-Schlitz, 5 mm breit, von der Oberkante bis zur Mitte
//     (z = hoehe/2) für die Sensor-Kabel
//   • Lüftung: viele kleine Bohrungen durch ALLE Seiten, auch die Rückwand
//     (um den Kabel-Schlitz herum) — lange Seiten, beide Stirnseiten, Boden und
//     Deckel. Die Löcher (Ø 2,5 mm) sind klein genug für einen Druck ohne
//     Stützstrukturen; die Raster sind so verdichtet, dass zusätzliche Löcher auf
//     den Kreuzungspunkten zwischen den bestehenden Reihen sitzen (der Abstand
//     bleibt aber groß genug, damit die Löcher nicht verschmelzen).
//
// Hinweis: Die Zugkanten-Rundung der Bibliothek skaliert jetzt mit der
//   Wandstärke (min(1, wand/2)), sodass der Deckel auch bei wand = 1 mm
//   funktioniert. Für Modelle mit wand ≥ 2 bleibt alles unverändert.
//
// Rendern:
//   openscad -o sensor_box.stl  -D 'teil=1'  sensor_box.scad
//   openscad -o sensor_lid.stl  -D 'teil=2'  sensor_box.scad
// =============================================================================

include <BOSL2/std.scad>
$fn = 48;

use <../../3d-models/schiebedeckel-box/schiebedeckel-box.scad>

// ---- Teilauswahl (per -D übersteuerbar) ----
teil = 1;   // 1 = kiste, 2 = deckel

// ---- Maße (alle mm) ----
breite    = 47;    // Außenbreite (x-Richtung)
tiefe     = 19;    // Außentiefe  (y-Richtung)
hoehe     = 21;    // Außenhöhe   (z-Richtung)
wand      = 1;     // Wandstärke (auch Boden und Deckel)
nut_tiefe = 0.4;   // Führungsnuttiefe — muss < wand sein
spiel     = 0.4;   // Spiel Deckel/Nut

// ---- Deckel-Unterkante (Position der Deckel-Lüftung) ----
// boden + stauraum = hoehe - 2*wand - spiel/2  (gleiche Formel wie die Bibliothek)
deckel_unten = hoehe - 2 * wand - spiel / 2;    // 18.8

// ---- Kabelführung ----
// Schlitz in der Rückwand (-x), 5 mm breit, von der Oberkante bis zur Mitte
kabel_b = 5;            // Breite des Kabel-Schlitzes (y-Richtung)
kabel_t = hoehe / 2;    // Tiefe ab Oberkante bis zur Mitte

// ---- Lüftungslöcher ----
loch_d      = 2.5;      // Lochdurchmesser (supportfrei: klein)
loch_rand   = 4;        // Abstand der äußersten Lochreihen zu den Kanten

// Lochraster (symmetrisch, verdichtet: zusätzliche Löcher auf den
// Kreuzungspunkten zwischen den bestehenden Reihen)
x_raster  = [-18, -13.5, -9, -4.5, 0, 4.5, 9, 13.5, 18];
y_boden   = [-6, 0, 6];
y_deckel  = [-6, 0, 6];
z_laeng   = [5, 10, 15];
y_plusx   = [-4, 0, 4];      // +x-Seite: zusätzliche mittlere Reihe
z_plusx   = [5, 11, 16];
y_minusx  = [-6, 6];         // -x-Seite (Kabelführung): beidseitig des Schlitzes
z_minusx  = [5, 10, 15];

module kabel_schlitz() {
    // Schlitz durch die Rückwand (-x), von der Oberkante bis zur Mitte
    translate([ -breite/2, 0, hoehe - kabel_t ])
        cuboid([ 2*wand + 4, kabel_b, kabel_t + 2 ], anchor = BOTTOM);
}

// Löcher durch beide Längswände (y = ±tiefe/2), Achse in y-Richtung
module lueftung_laengswaende() {
    for (x = x_raster)
        for (z = z_laeng)
            translate([ x, 0, z ])
                cyl(d = loch_d, h = tiefe + 2, orient = BACK);
}

// Löcher durch die +x-Seite (Einschubseite), nur unterhalb des Einschubschlitzes
module lueftung_plusx() {
    for (y = y_plusx)
        for (z = z_plusx)
            translate([ breite/2, y, z ])
                cyl(d = loch_d, h = 2*wand + 4, orient = RIGHT);
}

// Löcher durch die -x-Seite (Rückwand mit Kabel-Schlitz), beidseitig vom Schlitz
module lueftung_minusx() {
    for (y = y_minusx)
        for (z = z_minusx)
            translate([ -breite/2, y, z ])
                cyl(d = loch_d, h = 2*wand + 4, orient = RIGHT);
}

// Löcher durch den Boden (z = 0), Achse in z-Richtung
module lueftung_boden() {
    for (x = x_raster)
        for (y = y_boden)
            translate([ x, y, 0 ])
                cyl(d = loch_d, h = 2*wand + 4, orient = TOP);
}

// Löcher durch den Deckel (vertikal), Achse in z-Richtung
module lueftung_deckel() {
    for (x = x_raster)
        for (y = y_deckel)
            translate([ x, y, deckel_unten ])
                cyl(d = loch_d, h = 2*wand + 4, orient = TOP);
}

// Deckel — wird direkt aus der Bibliothek bezogen (die Zugkanten-Rundung
// skaliert dort jetzt mit der Wandstärke, siehe Hinweis oben)
if (teil == 1) {
    difference() {
        schiebedeckel_box(
            breite = breite, tiefe = tiefe, hoehe = hoehe,
            wand = wand, nut_tiefe = nut_tiefe, spiel = spiel,
            teil = "kiste"
        );
        kabel_schlitz();
        lueftung_laengswaende();
        lueftung_plusx();
        lueftung_minusx();
        lueftung_boden();
    }
} else {
    difference() {
        schiebedeckel_box(
            breite = breite, tiefe = tiefe, hoehe = hoehe,
            wand = wand, nut_tiefe = nut_tiefe, spiel = spiel,
            teil = "deckel"
        );
        lueftung_deckel();
    }
}

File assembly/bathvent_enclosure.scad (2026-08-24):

// =============================================================================
// bathvent_enclosure.scad — Gehäuse für bathvent (Bad-Lüftungssteuerung)
// =============================================================================
// Schiebedeckel-Box ("Domino"-Stil) auf Basis der Bibliothek
//   ../../3d-models/schiebedeckel-box/schiebedeckel-box.scad  (benötigt BOSL2)
//
// Außenmaße: 320 × 40 × 45 mm (Breite × Tiefe × Höhe), Wandstärke 2 mm.
// Aussparungen (nur in der Kiste / box):
//   • Gegenüberliegende Seite (-x): mittig ein Schlitz von der Oberkante abwärts,
//     gleich dem mittleren Schlitz (10 mm breit × 40 mm tief)
//   • Einschubseite (Deckel, +x): zwei Kabel-Schlitze von der Oberkante abwärts
//       – mittig:  10 mm breit × 40 mm tief
//       – links daneben (im Spalt zwischen Kante und mittlerem Schlitz):
//                   5 mm breit × 30 mm tief
//
// Rendern:
//   openscad -o bathvent_box.stl  -D 'teil=1'  bathvent_enclosure.scad
//   openscad -o bathvent_lid.stl  -D 'teil=2'  bathvent_enclosure.scad
// =============================================================================

include <BOSL2/std.scad>
$fn = 48;

use <../../3d-models/schiebedeckel-box/schiebedeckel-box.scad>

// ---- Teilauswahl (per -D übersteuerbar) ----
teil = 1;   // 1 = kiste, 2 = deckel

// ---- Maße (alle mm) ----
breite    = 320;   // Außenbreite (x-Richtung)
tiefe     = 40;    // Außentiefe  (y-Richtung)
hoehe     = 45;    // Außenhöhe   (z-Richtung)
wand      = 2;     // Wandstärke (auch Boden und Deckel)
nut_tiefe = 0.8;     // Führungsnuttiefe — muss < wand sein
spiel     = 0.4;   // Spiel Deckel/Nut

// ---- Aussparungen ----
schlitz_mitte_b = 10;      // Breite mittlerer Schlitz
schlitz_mitte_t = 40;      // Tiefe  mittlerer Schlitz (ab Oberkante)
schlitz_seite_b = 5;       // Breite seitlicher Schlitz
schlitz_seite_t = 30;      // Tiefe  seitlicher Schlitz (ab Oberkante)

module aussparungen() {
    // Schlitz wie der mittlere durch die Rückwand (-x), von der Oberkante abwärts
    translate([ -breite/2, 0, hoehe - schlitz_mitte_t ])
        cuboid([ 2*wand + 4, schlitz_mitte_b, schlitz_mitte_t + 2 ], anchor = BOTTOM);

    // Mittlerer Schlitz durch die Einschubseite (+x), von der Oberkante abwärts
    translate([ breite/2, 0, hoehe - schlitz_mitte_t ])
        cuboid([ 2*wand + 4, schlitz_mitte_b, schlitz_mitte_t + 2 ], anchor = BOTTOM);

    // Seitlicher Schlitz links vom mittleren, zentriert im Spalt zwischen
    // linker Kante (y = -tiefe/2) und mittlerem Schlitz (y = -schlitz_mitte_b/2)
    y_seite = (-tiefe/2 + -schlitz_mitte_b/2) / 2;
    translate([ breite/2, y_seite, hoehe - schlitz_seite_t ])
        cuboid([ 2*wand + 4, schlitz_seite_b, schlitz_seite_t + 2 ], anchor = BOTTOM);
}

if (teil == 1) {
    difference() {
        schiebedeckel_box(
            breite = breite, tiefe = tiefe, hoehe = hoehe,
            wand = wand, nut_tiefe = nut_tiefe, spiel = spiel,
            teil = "kiste"
        );
        aussparungen();
    }
} else {
    schiebedeckel_box(
        breite = breite, tiefe = tiefe, hoehe = hoehe,
        wand = wand, nut_tiefe = nut_tiefe, spiel = spiel,
        teil = "deckel"
    );
}

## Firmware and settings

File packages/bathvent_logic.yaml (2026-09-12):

# =============================================================================
# bathvent_logic.yaml — Hardware-independent control logic
# =============================================================================
# The controller is a small state machine implemented in bathvent.h/.cpp and
# described in docs/state-machine.md. All state persisted between ticks lives
# as a module global inside bathvent.cpp — ESPHome globals are no longer used.
#
# Every parameter is an MQTT "number" entity (settable, restore_value: true),
# and everything the controller keeps between ticks is published for insight.

# ---- Sensors (DHT20 + SGP40) ----

sensor:
  - platform: aht10
    variant: AHT20
    update_interval: 5s
    temperature:
      name: "Temperature"
      id: dht20_temperature
    humidity:
      name: "Humidity"
      id: dht20_humidity

  - platform: sgp4x
    update_interval: 5s
    store_baseline: true
    voc_index:
      name: "VOC Index"
      id: voc_index
    compensation:
      temperature_source: dht20_temperature
      humidity_source: dht20_humidity

# ---- State mirrors ----
# Everything the controller keeps between ticks is published from the interval
# lambda below: the change-check reference values and the age of each timestamp
# (which drives max_off_time, flush_duration, afterrun_duration and the check).

  - platform: template
    name: "Stored Humidity"
    id: stored_humidity
    unit_of_measurement: "%"
    accuracy_decimals: 2
    update_interval: never

  - platform: template
    name: "Stored VOC Index"
    id: stored_voc
    accuracy_decimals: 0
    update_interval: never

  - platform: template
    name: "Last Sensor Check Age"
    id: last_sensor_check_age
    unit_of_measurement: "s"
    accuracy_decimals: 0
    update_interval: never

  - platform: template
    name: "Last On Age"
    id: last_on_age
    unit_of_measurement: "s"
    accuracy_decimals: 0
    update_interval: never

  - platform: template
    name: "Afterrun Age"
    id: afterrun_age
    unit_of_measurement: "s"
    accuracy_decimals: 0
    update_interval: never

  - platform: template
    name: "Flush Age"
    id: flush_age
    unit_of_measurement: "s"
    accuracy_decimals: 0
    update_interval: never

binary_sensor:
  - platform: gpio
    pin:
      number: GPIO13
      mode: INPUT
      inverted: true
    name: "Light Switch"
    id: light_switch
    filters:
      - delayed_off: 100ms

# ---- Text sensors (state + trace) ----
# Publish-only sinks, refreshed every tick from the interval lambda below.
# "Trace" is the short per-tick trace; the full form goes to the log.

text_sensor:
  - platform: template
    name: "Fan State"
    id: fan_state
    update_interval: never

  - platform: template
    name: "Stage"
    id: stage
    update_interval: never

  - platform: template
    name: "Trace"
    id: trace
    update_interval: never

# ---- Relay outputs (cascade) ----
# Kaskade: Master (Ein/Aus), Full (Voll/Reduziert), LowMid (Low/Mid).
# Gelötete Verdrahtung: Full NC = voll (direkt via NTC), Full NO = reduziert
# (Kondensator-Bank); LowMid NO = 5uF (mid), LowMid NC = 3uF (low).
# De-energized Master = Motor aus (sicherer Boot-Zustand).

switch:
  - platform: gpio
    pin: GPIO14
    id: relay_master
    name: "Relay Master"
    restore_mode: RESTORE_DEFAULT_OFF

  - platform: gpio
    pin: GPIO16
    id: relay_lowmid
    name: "Relay LowMid"
    restore_mode: RESTORE_DEFAULT_OFF

  - platform: gpio
    pin: GPIO12
    id: relay_full
    name: "Relay Full"
    restore_mode: RESTORE_DEFAULT_OFF

# ---- Configurable parameters via MQTT ----
# The compiled defaults live in BathventConfig (bathvent.h) and the
# initial_value here must match. restore_value keeps the tuning across
# reboots — a stored value always wins over a changed default after flashing
# (set it once via MQTT or wipe the flash).
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

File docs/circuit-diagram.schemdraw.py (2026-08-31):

#!/usr/bin/env python3
# /// script
# requires-python = ">=3.10"
# dependencies = ["schemdraw>=0.23", "matplotlib"]
# ///
"""Circuit diagram for bathvent (Kaskaden-Schaltung der Relais).

Source of truth: README.md (BOM + Verdrahtungstabellen).

Layout:
  - Links:  Anschlüsse L (Dauerphase), LH (Lampenphase), N
  - Mitte:  Relais-Kaskade K1 (Master), K2 (Full), K3 (LowMid),
            NTC-Heißleiter, 3 µF / 5 µF Kondensatoren
  - Rechts: Lüfter (Spaltpolmotor) mit RC-Glied parallel
  - Unten:  Steuerteil (DC): Netzteil, Optokoppler, Relais-Module,
            ESP8266, Sensoren (DHT20/SGP40)

Anschlussnamen = README (IN/VCC/GND/OUT/SDA/SCL/VIN/5V...).
Versorgung: 5 V / 3,3 V als Vdd-Pfeil OBEN, GND als Erdungszeichen UNTEN
(an jedem IC/Modul; wird in ic() automatisch erzeugt).

Output: docs/circuit-diagram.svg (+ docs/circuit-diagram.png via Matplotlib)

Aufruf (uv run, beliebiges Verzeichnis; Dependencies per PEP 723 inline):
  uv run circuit-diagram.schemdraw.py        # aus docs/
  uv run docs/circuit-diagram.schemdraw.py   # aus dem Projekt-Root

Hinweis: `uvx` startet Tools (uv tool run), `uv run` startet Skripte --
fuer PEP-723-Skripte ist `uv run` der richtige Befehl.
"""

from pathlib import Path

import schemdraw
import schemdraw.elements as elm

# Ausgabeverzeichnis = Verzeichnis dieses Skripts (docs/), unabhaengig vom CWD,
# damit der Aufruf per uvx aus dem docs-Ordner oder aus dem Projekt-Root funktioniert.
OUT_DIR = Path(__file__).resolve().parent

UNIT = 2.0

# ---- helpers ----------------------------------------------------------------

def route(d, *pts):
    """Draw orthogonal polyline through the given (x, y) points."""
    for a, b in zip(pts, pts[1:]):
        d += elm.Line().at(a).to(b)

def dot(d, x, y):
    d += elm.Dot().at((x, y))


with schemdraw.Drawing(show=False) as d:
    d.config(unit=UNIT, fontsize=11)

    # =====================================================================
    #  230 V LEISTUNGSTEIL  (links -> rechts)
    # =====================================================================

    # ---- linke Anschlüsse (Leitungen kommen nur von rechts) ----
    # LH wird direkt gegenüber dem Optokoppler angebunden (unten, siehe AC->DC).
    d += elm.Dot(open=True).at((0, 12)).label('L', loc='top')
    d += elm.Dot(open=True).at((0, 6)).label('N', loc='top')
    d += elm.Label().at((-0.4, 13.6)).label('230 V Netz', loc='right')

    # ---- Relais-Kontakte (Kaskade) ----
    # COM-Pegel y = 12,  Umschaltkontakte: b = NO (oben), c = NC (unten)
    k1 = d.add(elm.SwitchSpdt2().anchor('a').at((5, 12)).label('K1\nMaster', loc='top'))
    k2 = d.add(elm.SwitchSpdt2().anchor('a').at((11, 12)).label('K2\nFull', loc='top'))
    k3 = d.add(elm.SwitchSpdt2().anchor('a').at((17, 12)).label('K3\nLowMid', loc='top'))
    d += elm.Label().at((11, 16.0)).label(
        'Kontakte: oben = NO (angezogen), unten = NC (abgefallen)', loc='center')

    # L -> K1 COM; K1 NO -> K2 COM; K2 NO -> K3 COM  (NO-Kette, oben)
    route(d, (0, 12), (k1.absanchors['a'].x, k1.absanchors['a'].y))
    route(d, (k1.absanchors['b'].x, k1.absanchors['b'].y),
             (k2.absanchors['a'].x, k1.absanchors['b'].y),
             (k2.absanchors['a'].x, k2.absanchors['a'].y))
    route(d, (k2.absanchors['b'].x, k2.absanchors['b'].y),
             (k3.absanchors['a'].x, k2.absanchors['b'].y),
             (k3.absanchors['a'].x, k3.absanchors['a'].y))

    # ---- Ausgänge zur Kondensator-/NTC-Bank (Lüfter-L-Sammelschiene) ----
    BUS_X = 23.0     # Lüfter-L-Sammelschiene
    FAN_X = 27.0     # Lüfter
    SNUB_X = 30.0    # RC-Glied (rechts vom Lüfter, parallel zum Motor)

    # K2 NC (voll/direkt) -> NTC -> Lüfter L
    k2c = k2.absanchors['c']
    route(d, (k2c.x, k2c.y), (k2c.x, 10.2))
    ntc = d.add(elm.Thermistor().at((k2c.x, 10.2)).to((17.5, 10.2))
                .label('NTC\n10 Ω', loc='bottom'))
    route(d, (17.5, 10.2), (BUS_X, 10.2))

    # K3 NO (mid) -> 5 µF -> Lüfter L   (direkt am NO-Kontakt)
    k3b = k3.absanchors['b']
    cap_mid = d.add(elm.Capacitor2().at((k3b.x, k3b.y)).to((22.0, k3b.y))
                    .label('5 µF', loc='top'))
    route(d, (22.0, k3b.y), (BUS_X, k3b.y))

    # K3 NC (low) -> 3 µF -> Lüfter L   (direkt am NC-Kontakt)
    k3c = k3.absanchors['c']
    cap_low = d.add(elm.Capacitor2().at((k3c.x, k3c.y)).to((22.0, k3c.y))
                    .label('3 µF', loc='bottom'))
    route(d, (22.0, k3c.y), (BUS_X, k3c.y))

    # Lüfter-L-Sammelschiene (vertikal, deckt alle Ausgänge ab)
    y_bus1 = 12.8
    route(d, (BUS_X, 10.2), (BUS_X, y_bus1))
    dot(d, BUS_X, 10.2)
    dot(d, BUS_X, k3c.y)
    dot(d, BUS_X, k3b.y)
    dot(d, BUS_X, y_bus1)

    # ---- Lüfter (Motor) rechts, vertikal: oben = L, unten = N ----
    fan = d.add(elm.Motor().up().at((FAN_X, 10)))
    fan_top = (fan.absanchors['end'].x, fan.absanchors['end'].y)      # L (oben)
    fan_bot = (fan.absanchors['start'].x, fan.absanchors['start'].y)  # N (unten)
    d += elm.Label().at((24.0, 10.0)).label('Lüfter\n(Spaltpol-\nmotor)', loc='right')

    # Lüfter L: Sammelschiene -> rechts -> oben zum Motor
    route(d, (BUS_X, y_bus1), (fan_top[0], y_bus1), (fan_top[0], fan_top[1]))
    # Lüfter N: N-Schiene -> rechts -> unten zum Motor
    route(d, (fan_bot[0], 6), (fan_bot[0], fan_bot[1]))
    dot(d, fan_bot[0], 6)

    # ---- N-Schiene (y = 6, bis unter das RC-Glied) ----
    route(d, (0, 6), (SNUB_X, 6))

    # ---- RC-Glied (R + C in Reihe) parallel zum Lüfter ----
    # Oben am Lüfter-L (Motor L), unten an die N-Schiene (Motor N)
    route(d, fan_top, (SNUB_X, fan_top[1]))
    d.add(elm.ResistorIEC().down().at((SNUB_X, fan_top[1])).to((SNUB_X, fan_top[1] - 2.4)))
    d.add(elm.Capacitor2().down().at((SNUB_X, fan_top[1] - 2.4)).to((SNUB_X, fan_top[1] - 4.8)))
    route(d, (SNUB_X, fan_top[1] - 4.8), (SNUB_X, 6.0))
    dot(d, SNUB_X, fan_top[1])
    dot(d, SNUB_X, 6.0)
    d += elm.Label().at((SNUB_X + 0.8, fan_top[1] - 1.2)).label('100 Ω', loc='left')
    d += elm.Label().at((SNUB_X + 0.8, fan_top[1] - 3.6)).label('0,1 µF', loc='left')
    d += elm.Label().at((SNUB_X + 0.8, fan_top[1] + 0.6)).label('RC-Glied\n(parallel)', loc='left')

    # =====================================================================
    #  STEUERTEIL (DC) — Versorgung OBEN (Vdd-Pfeil) / GND UNTEN (Erdung)
    #  Die Versorgungs-Fahnen werden in ic() automatisch erzeugt.
    # =====================================================================
    d += elm.Label().at((2.5, 0.4)).label('Steuerung (5 V DC)', loc='center')
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

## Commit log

2026-08-04 Anpassungen und Präisierungen in README nach Experementieren
2026-08-05 Finale (vor der Implementierung) Anpassung der README in Diskussion mit AI
2026-08-05 Initialer Check-In der generierten Sourcen
2026-08-08 Hinweis zum Motor
2026-08-09 Implementierung auf 3 Relais umgestellt, da vorherige mit 2 nicht wie gedacht funktioniert hat. README angepasst und verkürzt
2026-08-09 i2c frequenz reduziert um die verbindung zu den sensoren stabiler zu machen
2026-08-09 reduziert die i2c frequenz um stabilität zu erhöhen und erhöht die abtast rate um leichter testen zu können
2026-08-11 Relais als eine Kaskade implementiert, sonst schließt ein Relais die Kondesatoren kurz, was zur Beschädigung des Relais führt
2026-08-11 verbessert stückliste und verdrahtung
2026-08-13 angepasst Beschreibung/Implementierung and die tasächlicher Verlötung der neuen Kaskaden-Variante
2026-08-17 der sgp40 sensor ist jetzt optional
2026-08-17 refactored fail-safe mode: jetzt benimmt sich der vent wie ein went ohne sensor
    [bathvent.h, bathvent_logic.yaml]
2026-08-23 Gehäuse erstellt
    [bathvent_enclosure.scad]
2026-08-24 finale box für die steuerung
    [bathvent_box.stl, bathvent_enclosure.scad, bathvent_lid.stl]
2026-08-27 gefixt das problem der feuchtigkeit beim langen baden
    [bathvent.h]
2026-08-28 optimiziert die feuchtigkeit regulierung
2026-08-28 3d box für sensoren
    [bathvent_box.stl, bathvent_lid.stl, sensor_box.scad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]
2026-08-30 verbesserungen in der feuchtigkeit absenkung logik
2026-08-30 fixed setzen der humidity baseline
    [bathvent_logic.yaml]
2026-09-04 verhindern dass der luft ruckflüss von aussen die werte verfälschen kann
2026-09-11 designing new worklfow as the current one is unstable and complicated
